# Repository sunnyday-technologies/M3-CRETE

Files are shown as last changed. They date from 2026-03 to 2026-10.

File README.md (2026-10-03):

# M3-CRETE — Experimental Open-Hardware Concrete/Paste Printing Reference

**A meter-scale cartesian motion reference for qualified technical teams working
with cementitious material extrusion in controlled R&D, laboratory, or
supervised institutional settings.**

M3-CRETE is an experimental open-hardware reference design, not a consumer
product, hobby kit, finished machine, certified construction printer, or
structural concrete production system.

Read first:

- [Safety Notice](SAFETY_NOTICE.md)
- [Electrical Scope Boundary](ELECTRICAL_SCOPE_BOUNDARY.md)
- [Disclaimer](DISCLAIMER.md)

The public release is limited to mechanical design information, low-voltage
control-interface references, and software/firmware references where published.
It does not include AC mains wiring instructions, control-panel build
instructions, facility-connection instructions, safety-rated emergency-stop
circuit designs, 48 V high-current distribution design, or code-compliance
instructions.

**M³** = **M**obile · **M**odular · **M**eter³



Developed by [Sunnyday Technologies](https://sunn3d.com).

| Spec | Value |
|---|---|
| **Open BOM component target** | Under $5,000 for public mechanical/low-voltage reference components where current commodity pricing and substitutions allow; professional electrical/power-control scope is excluded |
| **Configured design envelope** | Default M3-2 target: 2000 × 1000 × 1000 mm. The assembled external footprint and shipping configuration have not been physically verified here. |
| **Printhead weight** | ~1.5 kg |
| **License** | CERN-OHL-W-2.0 |

---

## Why M3-CRETE

Most concrete 3D printers are either proprietary industrial systems or one-off
research machines tied to specific institutions. M3-CRETE targets the space
between: an open mechanical and controls reference that qualified teams can
study, adapt, and validate within their own controlled research or development
programs.

### Target Applications

- Non-structural research specimens
- Process-development articles
- Digital formwork, molds, and fixtures
- Controlled materials and toolpath studies
- Laboratory and supervised institutional demonstrations
- Non-structural prototype objects where separately reviewed

Printed outputs require separate physical validation. No printed output from an
M3-CRETE-derived system may be used for structural, load-bearing, life-safety,
building-code, transportation, water-control, pressure-containing, occupied,
public-access, or permanent construction use unless separately designed, tested,
permitted, and approved by the responsible licensed professionals and
authorities for that specific project.

---

## Design Principles

### Mechanical Rigidity, Serviceability

The frame is engineered closer to CNC machine standards than desktop 3D
printers: rigid, durable, and precise. Mechanical components use standard
aluminum extrusions and commodity hardware where practical, so qualified teams
can inspect, replace, and modify parts without single-source dependency.

### Lower Moving Mass, Still Hazardous

The current drive system is sized for the reference geometry using project
calculations and component assumptions that still require physical commissioning
and load validation. This does not make the machine safety-rated or safe for
unsupervised use. Moving axes, pinch/crush hazards, cementitious materials,
pressurized hoses, electrical systems, and software-controlled motion all
require qualified review, guarding, PPE, training, and operating procedures.

### No Thermoplastic Melt System

Cementitious materials harden through hydration rather than thermoplastic melting and cooling, so the reference design does not use an FDM-style heated bed, hot end, or part-cooling system. That removes one class of hardware, but this repository does not establish a quantified cost, energy, or reliability advantage over other printer architectures.

### Designed for Research Iteration

Some non-structural components such as brackets, guides, and enclosure parts are
designed to be 3D-printable. Those printed parts still require inspection,
material selection, and project-specific validation before use in a working
machine.

---

## Firmware and Software Compatibility

M3-CRETE runs on established open-source toolchains. No proprietary software required.

| Layer | Compatible Tools |
|---|---|
| **Firmware** | Marlin, Klipper |
| **Slicers** | Cura, OrcaSlicer, PrusaSlicer |
| **Controls** | Standard stepper drivers, common control boards |
| **CAD/CAM** | Any tool that exports STL, OBJ, or 3MF |

Standard G-code workflows provide full, transparent control over toolpaths, layer heights, and extrusion parameters.

Firmware configurations are maintained separately:
[M3-CRETE-FIRMWARE](https://github.com/sunnyday-technologies/M3-CRETE-FIRMWARE)

---

## Repository Structure

```
M3-CRETE/
├── CAD/
│   ├── M3-2_Assembly.step       # Development STEP assembly snapshot via LFS
│   ├── m3_2_assembly.py         # CadQuery assembly generator (source of truth)
│   ├── self_check.py            # 5-gate automated validation harness
│   ├── kinematics_eval.py       # Structural analysis (deflection, torque, belts)
│   ├── Custom/                  # 3D-printable brackets (STEP + STL)
│   ├── Components/              # OpenBuilds parts library (CC BY-SA 4.0)
│   └── Advanced/                # Extended parts (C-beam, joining plates)
├── bom/
│   ├── data.json                # BOM source of truth (v2.7.0; 65 reference entries)
│   └── index.html               # Interactive BOM viewer (bom.m3-crete.com/bom)
├── firmware/                    # Klipper configs (kinematics, steppers)
├── blog/                        # Build logs and project updates
└── config.js                    # Model variants (M3-1, M3-2, M3-4)
```

### AI-Assisted CAD Workflow

This project uses [CADCLAW](https://github.com/sunnyday-technologies/CADCLAW), an automated checking framework for STEP CAD developed during this project. A declarative assembly spec places authored STEP parts by connector frames and datum chains, while software checks inspect selected inventory, interference, adjacency, dimensional, orientation, and floating-part rules. CADCLAW places parts authored in native CAD; it does not generate geometry. These checks are bounded software evidence, not proof of manufacturability, structural performance, tolerance compliance, safety, or physical fit.

See the [CADCLAW repo](https://github.com/sunnyday-technologies/CADCLAW) for the generalized, reusable framework.

---

## Material Compatibility

M3-CRETE is a hardware reference, not a materials approval. It does not
prescribe a construction mix, validate printed outputs, or certify any
cementitious formulation for field use. Mixes, toolpaths, curing, durability,
and acceptance criteria require separate physical testing and professional
review for each use case.

For early-stage materials-evidence and mix-design decision support, see
[CEMFORGE](https://cemforge.ai/concrete-printers/). Where sufficient source
evidence exists, it can help organize candidate formulations for review; it does
not establish a mix's performance or fitness. Every candidate requires physical
testing, provenance review, and qualified approval before project use.

---

## Project Status

M3-CRETE is in active development. Current focus areas:

- Finalizing the open BOM and build documentation
- Validating open assembly notes and build sequence
- Establishing firmware profiles for concrete-specific extrusion parameters

Interested in contributing design feedback, supplier corrections, or controlled
build notes?
Open an issue or start a GitHub discussion.

---

## Disclaimer

M3-CRETE is provided as-is for experimental, educational, and development
purposes. Concrete/paste printing involves moving machinery, cementitious
materials, pressurized material handling, and electrical systems that pose real
safety risks. Users assume all responsibility for safe design, construction,
commissioning, guarding, training, inspection, and operation of any system built
from these files.

### Electrical / AC Mains Boundary

Any AC mains wiring, control-box integration, grounding, bonding, overcurrent
protection, disconnects, emergency-stop power circuits, facility connection,
inspection, or code compliance work must be performed by qualified personnel, a
licensed electrician where required, or a qualified control-panel shop.

The public M3-CRETE files may identify electrical interfaces, low-voltage
controls, and component references, but they are not AC mains wiring
instructions, control-panel build instructions, or a substitute for applicable
electrical codes, authority-having-jurisdiction review, or professional
electrical judgment.

See [SAFETY_NOTICE.md](SAFETY_NOTICE.md),
[ELECTRICAL_SCOPE_BOUNDARY.md](ELECTRICAL_SCOPE_BOUNDARY.md), and
[DISCLAIMER.md](DISCLAIMER.md) for full details.

---

## License

This project is licensed under the **CERN Open Hardware Licence Version 2 — Weakly Reciprocal** ([CERN-OHL-W-2.0](https://ohwr.org/cern_ohl_w_v2.txt)).

You may use, modify, and distribute this design under the terms of that license. Modifications to covered files must be made available under the same license. This project includes no warranty of any kind.

**Dual License Notice:** V-Slot component CAD models in `CAD/Components/` are based on [OpenBuilds](https://openbuilds.com) designs and are licensed under [CC BY-SA 4.0](https://creativecommons.org/licenses/by-sa/4.0/). All other project files (custom parts, BOM viewer, firmware configs, documentation) are licensed under CERN-OHL-W-2.0.

See [LICENSES/](LICENSES/) for full license texts.

---

## Related Projects and Resources

| Resource | Description |
|---|---|
| [Convergence Engineering whitepaper](https://doi.org/10.5281/zenodo.19863080) | Methodology paper that uses M3-CRETE as a public case study; introduces the *time to silence* metric. CC BY 4.0 preprint, Zenodo. |
| [Sunnyday Technologies](https://sunn3d.com) | Parent company — concrete 3D printing and engineered cementitious composites |
| [M3-CRETE Project Page](https://sunn3d.com/m3-crete/) | Hosted project overview and Sunnyday contact path |
| [CADCLAW](https://github.com/sunnyday-technologies/CADCLAW) | Automated STEP assembly compilation and validation, extracted from this project |
| [CEMFORGE™](https://cemforge.ai/concrete-printers/) | AI-powered concrete formulation platform by Sunnyday Technologies |
| [M3-CRETE Firmware](https://github.com/sunnyday-technologies/M3-CRETE-FIRMWARE) | Firmware configurations for Klipper |

---

## Author

**Nicholas Sonnentag** ([ORCID 0009-0002-1897-384X](https://orcid.org/0009-0002-1897-384X)) — mechanical engineer, founder of [Sunnyday Technologies](https://sunn3d.com). M3-CRETE is designed and maintained by Nick; CAD iteration is LLM-assisted but the engineering judgment, component selection, build decisions, and direction are his.

- LinkedIn: [Nicholas Sonnentag](https://www.linkedin.com/in/nicholas-sonnentag)
- Email: `info@sunn3d.com`

## Citation

If you use M3-CRETE designs in research, a controlled build, or derivative
work, please cite:

```
Sonnentag, N. (2026). M3-CRETE: Open-Source Concrete 3D Printer.
Sunnyday Technologies.
https://doi.org/10.5281/zenodo.19647435
```

For the methodology paper that uses M3-CRETE as a public case study, cite:

```
Sonnentag, N. (2026). Convergence Engineering: Commissioning Autonomous
Software by Measuring the Rate at Which Novel Failures Trend Toward Zero.
Sunnyday Technologies. https://doi.org/10.5281/zenodo.19863080
```

A [`CITATION.cff`](CITATION.cff) file is included for automated citation tooling.

## Contributing

We welcome issues, pull requests, and design feedback from qualified teams. If
you are working with cementitious extrusion in a controlled technical setting,
your experience is valuable — open an issue or start a
[discussion](https://github.com/sunnyday-technologies/M3-CRETE/discussions).

**Contact:** info@sunn3d.com

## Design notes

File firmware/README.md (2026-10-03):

# M3-CRETE Firmware

Klipper configuration for the M3-CRETE concrete 3D printer motion system.

## What's in this directory

| File | Purpose |
|---|---|
| `printer.cfg` | Top-level entry point — includes every other file |
| `mcu.cfg` | BTT Kraken MCU connection (serial path) |
| `kinematics.cfg` | Cartesian kinematics, build volume, motion limits |
| `steppers.cfg` | 7 motion steppers (X, 2×Y, 4×Z) + extruder/pump |
| `tmc.cfg` | TMC5160 driver settings — currents, StallGuard thresholds |
| `homing.cfg` | Sensorless homing sequence (no physical endstops) |
| `z_tilt.cfg` | Quad Z self-tramming |
| `macros.cfg` | START_PRINT, END_PRINT, pump priming, pump flush, pressure advance |
| `input_shaper.cfg` | ADXL345 + resonance tester + input shaper (optional include) |

## Hardware assumed

- **Controller:** BTT Kraken v1.0 (STM32H723, 8× onboard TMC5160)
- **Host:** Raspberry Pi 5 8GB running Klipper + Moonraker + Mainsail
- **Motion steppers:** 7× NEMA23 3–4.5Nm, 8mm shaft (1×X + 2×Y + 4×Z)
- **Nozzle valve:** 1× small stepper (NEMA17/23) on Kraken DRIVER7
- **Feed pump:** 1× NEMA34 on external driver (owner-supplied)
- **Y/Z belts:** GT2 10mm + 20-tooth pulleys (looped)
- **X belt:** GT2 6mm + 20-tooth pulley (fixed strand, pinion drive)
- **V-wheels:** Polycarbonate, eccentric-spacer adjustable
- **Homing:** Sensorless StallGuard on all axes — no physical endstops

## Axis conventions & motor layout

Frame origin `(0, 0, 0)` is at the **front-left corner of the build surface**. Looking down from above:

```
              X=0                                      X=2000
             ┌──────────────────────────────────────────┐    Y=1000
             │ Z2◆                                 Z3◆ │    (REAR)
             │                                          │
             │                                          │  ← Y motors
             │                                          │    (2× at rear,
             │                                          │     inboard of
             │           BUILD VOLUME                   │     rear Z-posts)
             │         2000 × 1000 × 1000 mm             │
             │                                          │
             │                                          │  ← X motor
             │                                          │    on X-carriage
             │                                          │    (pinion drive,
             │                                          │     travels with
             │ Z0◆                                 Z1◆ │     the printhead)
             └──────────────────────────────────────────┘    Y=0
                                                             (FRONT, HOME)

             ← X−                                     X+ →
                HOME

  ◆ = Z motor (NEMA23) on top brace, straddling each 4080 C-beam Z-post
      (4 motors total, each with its own StallGuard-based homing)
```

### Home positions (all sensorless — no physical endstops)

| Axis | Home direction | Home position | Stall target |
|---|---|---|---|
| X | toward X− | X = 0 | left frame post |
| Y | toward Y− | Y = 0 | front Z-posts frame |
| Z | toward Z+ | Z = 1000 | top brace (per post)|

**Homing sequence** (set in `homing.cfg`):

1. **Z first** — all 4 Z posts drive UP into the top brace in parallel. Each post's StallGuard fires independently on its own driver, giving per-corner coplanarity without a physical probe.
2. **X second** — the development sequence assumes Z reached its configured reference position before an X-axis stall-detection move; this is not a verified safe-height guarantee.
3. **Y last** — both Y motors drive the gantry forward into the front frame until the primary stalls (the secondary follows).

### Why Z first

If X or Y moves with Z at an unknown position, the printhead can contact an obstacle. The current development sequence attempts to establish a Z reference first, but stall sensing and a hard stop do not guarantee clearance, repeatability, safe force, or a clear path. A qualified commissioning plan must verify the actual envelope, obstructions, speeds, currents, stopping behavior, guarding, and recovery before any automated homing sequence is enabled.

### Development motion references (not validated safe limits)

| Parameter | Value | Notes |
|---|---|---|
| `max_velocity` | 100 mm/s | Tune up after input shaping |
| `max_accel` | 1500 mm/s² | Concrete mass demands gentle accel |
| `max_z_velocity` | 25 mm/s | Z belts, not leadscrews |
| `max_z_accel` | 300 mm/s² | |
| `square_corner_velocity` | 5.0 mm/s | Low to prevent belt slip on corners |

## Build from source (Klipper firmware for the Kraken)

On the Raspberry Pi:

```bash
cd ~
git clone https://github.com/Klipper3d/klipper.git
cd klipper
make menuconfig
```

In `menuconfig`, set:

```
Micro-controller Architecture ........... STMicroelectronics STM32
Processor model ......................... STM32H723
Bootloader offset ....................... 128KiB bootloader
Clock Reference ......................... 25 MHz crystal
Communication interface ................. USB (on PA11/PA12)
```

Save and exit, then:

```bash
make
```

The compiled firmware lands at `~/klipper/out/klipper.bin`.

## Flashing the Kraken

1. Copy `klipper.bin` to a FAT32-formatted microSD card, renaming it to `firmware.bin`.
2. Power off the Kraken.
3. Insert the SD card.
4. Power on — the bootloader will flash automatically (~10 seconds).
5. On successful flash, `firmware.bin` will be renamed to `FIRMWARE.CUR` on the card.

## Installing this config

1. Copy this entire `firmware/` directory to `~/printer_data/config/` on the Pi.
2. Rename `printer.cfg` to the name Moonraker expects (default: `printer.cfg` in that directory — leave it as-is if you copied the folder contents directly).
3. Edit `mcu.cfg` — replace the `XXXXXXXXXXXXXXXX` placeholder with the real serial ID. Find it with:

   ```bash
   ls /dev/serial/by-id/
   ```

4. Restart Klipper via Mainsail (**Machine** → **Restart**) or:

   ```bash
   sudo systemctl restart klipper
   ```

## First-boot checklist

Do these in order, one at a time, before any actual printing.

### 1. Verify MCU connection

```
RESTART
FIRMWARE_RESTART
```

Klipper should report "Ready" in Mainsail. If it errors, check the serial path in `mcu.cfg`.

### 2. Power on one stepper at a time, verify motion direction

Using the Mainsail jog buttons, move each axis 10mm in its positive direction. Confirm:

- **X+** moves the gantry toward the **right** (looking at the front of the machine)
- **Y+** moves the gantry toward the **rear**
- **Z+** moves the gantry **up**

If any axis moves the wrong way, flip the `dir_pin` polarity in `steppers.cfg` by adding or removing the `!` prefix.

### 3. Verify Y dual-drive synchronization

Jog Y by 100mm. The left and right Y rails must move together — if one lags, they're not synced. Check that `stepper_y1` has the same `rotation_distance` and `microsteps` as `stepper_y`.

### 4. Calibrate rotation_distance per axis

Mark a starting point with tape. Jog the axis exactly 100mm via Mainsail. Measure with a tape measure. If the actual distance is off, adjust `rotation_distance` proportionally:

```
new_rotation_distance = old_rotation_distance × (actual / requested)
```

### 5. Tune StallGuard thresholds (sensorless homing)

This is the trickiest part. For each axis, iterate:

1. Issue `G28 X` (or Y or Z).
2. Watch the motion:
   - **Stalls before reaching the frame** → `driver_SGT` is too sensitive → **increase** by 1 in `tmc.cfg`
   - **Crashes into the frame without stalling** → `driver_SGT` is not sensitive enough → **decrease** by 1
3. Restart Klipper (`FIRMWARE_RESTART`) after each change.
4. Repeat until homing stops reliably at the frame.

Use the `SHOW_SG` macro to see live StallGuard values while the printer is idle.

### 6. Test quad Z homing

The first `G28 Z` will drive all 4 Z posts UP into the top brace. Each post stalls independently when its corner meets the brace — you should hear 4 distinct "thunks" over about a second. If one corner doesn't stall, its `driver_SGT` is too high; lower it.

### 7. Calibrate the nozzle valve and feed pump independently

Because the two steppers are synced, you have to calibrate them one at a time.

**Step 7a — Feed pump (`pump_feed`):**

1. `PUMP_UNSYNC` (disconnect the pump from the valve)
2. Disconnect the hose from the nozzle and route it into a measuring cup
3. `G1 E100 F60` (runs only the pump, valve stays closed)
4. Measure the output volume
5. Scale: `new_rotation_distance = old × (commanded / actual)`
6. Edit `steppers.cfg` → `[extruder_stepper pump_feed]` → `rotation_distance`
7. `FIRMWARE_RESTART`
8. `PUMP_RESYNC`

**Step 7b — Nozzle valve (`extruder`):**

1. With hose reconnected and pump running synced, command `G1 E100 F60`
2. Measure what comes out the nozzle
3. If pump output is already calibrated and valve output is off, scale the valve's `rotation_distance` (in `[extruder]`) using the same formula
4. `FIRMWARE_RESTART`

In practice the valve rarely needs precise calibration — it's a metering gate, not a volumetric pump — but doing both ensures the two are in agreement.

### 8. Test a small print

Use a 10cm × 10cm single-wall square at a slow speed (30 mm/s) for the first print. Check:

- First-layer adhesion and squish
- Belt tension (no slapping or visible stretch under accel)
- Pump flow consistency

## Pump architecture — feed pump + nozzle valve

M3-CRETE uses a two-stage fluid-handling system:

- **Feed pump** (`pump_feed`) — the big NEMA34 upstream of the hose. Has its own pressure advance (typical 0.5–1.5 seconds) to pressurize the hose ahead of valve commanded moves. Runs on an external driver via Kraken's MOTOR7 header.
- **Nozzle valve** (`extruder`) — a small, fast actuator at the printhead. Pressure advance = 0. Effectively a metering valve with ~1 % retraction capability for clean corners. Runs on Kraken's DRIVER7 onboard TMC5160.

Both steppers are synchronized: every `G1 E...` move drives both at once. The feed pump runs *ahead* of the valve in time (by the amount of its pressure advance) so material arrives at the valve exactly when it opens.

### Why independent pressure advance matters

Concrete hoses are compressible and viscous — unlike a rigid FDM filament path, the pressure in the hose lags the pump by hundreds of milliseconds. If you drove the pump and valve with the same PA, the valve would either dribble (if PA is low) or over-pressurize at corners (if PA is high). Splitting them means:

- **Valve PA = 0** → opens and closes on time, clean corners
- **Pump PA = 0.8** → hose is already pressurized when the valve opens

### Tuning

Use the `SET_PUMP_PA` macro during a test print:

```
SET_PUMP_PA ADVANCE=0.5    ; start here
; print a corner-test pattern, observe
SET_PUMP_PA ADVANCE=0.8    ; increase if corners dribble after direction change
SET_PUMP_PA ADVANCE=0.3    ; decrease if corners bulge before direction change
```

The default in `START_PRINT` is `ADVANCE=0.8`. Edit `macros.cfg` once you've found your hose's sweet spot.

### Independent pump control

To run the feed pump solo (e.g. manually fill the hopper without opening the valve):

```
PUMP_UNSYNC           ; feed pump disconnects from valve
; jog pump manually via G1 E... — only pump moves
PUMP_RESYNC           ; feed pump reconnects for normal printing
```

## Safety notes

- **Flush the pump line within 5 minutes of print completion.** Concrete cures inside the line and will lock the pump solid.
- **StallGuard homing is not foolproof.** If you're standing inside the machine's envelope, always power off the motors first.
- **Test all motion at low current first** (`run_current: 1.2` in `tmc.cfg`) and raise in 0.2A increments after verifying thermal behavior.
- **The X axis is 2m long and heavy.** Homing speeds above 30 mm/s will cause belt slip before the frame is reached.

## Input shaping (ADXL345)

A 2m concrete printer has long belt spans that resonate at low frequencies — without input shaping, corner moves leave visible ringing for several cm. The `input_shaper.cfg` file is a drop-in module that enables Klipper's resonance measurement + compensation workflow using an ADXL345 accelerometer wired to the Raspberry Pi's GPIO SPI bus.

**Setup is a three-step thing:**

1. **Buy the part** — it's BOM item 71 (ADXL345, ~$10 from BTT/Adafruit/Amazon). Mount it rigidly to the printhead or X-carriage using M3 screws. Zip ties will give you garbage data.

2. **Wire it** — 6 wires from the breakout to the Pi's 40-pin header. The full pinout is in `input_shaper.cfg` at the top of the file. TL;DR: power + SPI on Pi pins 1, 9, 19, 21, 22, 23.

3. **Enable the include** — uncomment the `[include input_shaper.cfg]` line in `printer.cfg`, then follow the setup procedure inside `input_shaper.cfg` (enable SPI on the Pi, install the host MCU, run `SHAPER_CALIBRATE`).

Klipper's `SHAPER_CALIBRATE` will sweep the printer and print recommended `shaper_freq_x` / `shaper_freq_y` values. Paste those into the `[input_shaper]` section at the bottom of `input_shaper.cfg` and `FIRMWARE_RESTART`.

After tuning, you can leave the ADXL345 installed or remove it — the input shaper values stay in the config either way.

## Known limitations (v0.1)

- **No physical probe** — Z_TILT_ADJUST is stubbed out until a probe is wired in. First-layer calibration is currently manual.
- **Pin assignments for BTT Kraken are based on the upstream `example-kraken.cfg`** — verify against your board revision on first boot.
- **Extruder `rotation_distance` is a placeholder** — must be calibrated against your specific pump geometry.
- **Input shaping not yet tuned.** Add an ADXL345 to the toolhead mount and run `SHAPER_CALIBRATE` after mechanical commissioning.

## Contributing

This config is part of the M3-CRETE project: <https://github.com/sunnyday-technologies/M3-CRETE>

Licensed under CERN-OHL-W-2.0. Issues and PRs welcome at the repo above.

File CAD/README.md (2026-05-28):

# M3-CRETE CAD Files

3D models for the M3-CRETE concrete 3D printer motion system.

## Assembly (Draft v0.1 — In Development)

The M3-2 digital twin assembly is generated programmatically from the STEP
component library using CadQuery + Python. This is believed to be the first
AI-assisted multi-part mechanical assembly generated from real vendor STEP files.

**Status:** Draft v0.1 — frame structure complete, motion system in progress.

### Source of Truth: `m3_2_assembly.py`

`CAD/m3_2_assembly.py` is the **canonical source** for the M3-2 assembly. The
`.step` files in this directory (and any `.f3d`) are **derived outputs**
generated by running the script — they are not the source.

To modify the design, edit parameters in `m3_2_assembly.py` and regenerate the
STEP. Do **not** hand-edit the STEP files and expect changes to persist; the
next regen will overwrite them.

This satisfies the CERN-OHL-W-2.0 requirement to distribute the preferred form
for modification: the parametric Python script is human-readable, diffable, and
tool-agnostic — a better open-source workflow than shipping a binary Fusion 360
file that requires a specific version of proprietary software to open.

```
python CAD/m3_2_assembly.py          # Generates M3-2_Assembly.step
python CAD/parametric_extrusions.py  # Generates custom-length extrusions
python CAD/deep_probe.py             # Inspects STEP geometry for assembly math
```

**Requirements:** Python 3.11 + CadQuery 2.7.0 (`pip install cadquery`)

**Assembly contents (40 parts):**
- 4x C-Beam 4080 posts (1000mm, full height)
- 8x C-Beam 4080 top X-rails (1000mm segments, spliced)
- 5x C-Beam 4080 Y-braces (1000mm)
- 2x C-Beam 4080 Y-rails (1000mm)
- 2x C-Beam 4080 gantry beam (1000mm, spliced to 2000mm)
- 8x gantry plates (Z-carriage, sandwich posts)
- 4x gantry plates (X-carriage + Y-rail end plates)
- 7x NEMA23 motors (4Z horizontal + 2Y inside + 1X on carriage)
- 4x motor mount plates

**Open-bottom bridge frame** — no front/back bottom rails, allowing the printer
to straddle walls for continuous printing.

## Directory Structure

```
CAD/
├── Components/     Standard parts (OpenBuilds-compatible, CC BY-SA 4.0)
│   ├── V-Slot/         Extrusion profiles (4080 C-Beam primary)
│   ├── Plates/         Gantry plates, motor mounts, idler plates
│   ├── Wheels/         V-wheels (Delrin, Xtreme, idler pulleys)
│   ├── Bearings/       625-2RS, 688Z ball bearings
│   ├── Brackets/       Corner brackets, actuator end mounts
│   └── Hardware/       Eccentric spacers, shims, T-nuts
├── Custom/         Sunnyday-designed parts (CERN-OHL-W-2.0)
│   ├── Frame-Stiffener.step
│   └── Extruder-Mount-NPT.step
└── Advanced/       Compatible hardware for extended builds
    └── (alternative extrusion profiles, reinforcement options)
```

## Format

Component parts (`Components/`, `Advanced/`) and custom parts (`Custom/`) are
provided in **STEP** format (.step / .stp) for maximum compatibility with
FreeCAD, Fusion 360, SolidWorks, Onshape, and other CAD tools.

The **M3-2 assembly itself** uses the parametric Python script
(`m3_2_assembly.py`) as its source format, with `M3-2_Assembly.step` as the
generated output (see "Source of Truth" above).

## Component Parts — Sources

The standard V-Slot components in `Components/` are based on the [OpenBuilds](https://openbuilds.com) parts ecosystem, licensed under **CC BY-SA 4.0**.

### Where to Get STEP Files

If a part is not yet in this repo, you can download STEP models from:

| Source | URL | Notes |
|---|-----|---|
| **GrabCAD — OpenBuilds Gantry Set** | [grabcad.com/library/openbuilds-v-slot-gantry-set-all-sizes-1](https://grabcad.com/library/openbuilds-v-slot-gantry-set-all-sizes-1) | Complete gantry assemblies, all V-Slot sizes |
| **GrabCAD — V-Slot Tag** | [grabcad.com/library/tag/v-slot](https://grabcad.com/library/tag/v-slot) | Individual parts and assemblies |
| **Printables — Universal Gantry Plate** | [printables.com/model/459195](https://www.printables.com/model/459195-openbuilds-v-slot-gantry-plate-universal) | STL for 3D printing |
| **StepperOnline — NEMA23 Models** | [omc-stepperonline.com/download](https://www.omc-stepperonline.com/download) | Motor STEP files by MPN |
| **BTT — Kraken Board** | [github.com/bigtreetech/Kraken](https://github.com/bigtreetech/Kraken/tree/master/Hardware) | Controller board models |

### M3-CRETE Part Count

The M3-2 uses approximately **20 unique component types** (many repeated):

| Component | Unique Models | Total Qty |
|---|---|---|
| C-Beam 4080 extrusions | 1 (4080 C-Beam) | ~17 segments |
| Gantry/carriage plates | 3 types | 12 plates |
| Motor mounts | 1 type | 8 mounts |
| V-wheels | 2 types | 36 wheels |
| GT2 pulleys | 2 types | 20 pulleys |
| Bearings/spacers | 3 types | 28+ pieces |
| Custom parts | 2 (stiffener, extruder mount) | 5 parts |

## License

- **Components/** — CC BY-SA 4.0 (based on OpenBuilds designs, attribution required)
- **Custom/** — CERN-OHL-W-2.0 (same as M3-CRETE project)
- **Advanced/** — Mixed, see individual files

## Contributing

**To modify the M3-2 assembly:** Edit `m3_2_assembly.py` (the canonical
source), regenerate `M3-2_Assembly.step`, and commit both. Do not edit the
STEP directly.

**To add a new component model:**
1. Export as STEP (.step or .stp)
2. Name it to match the BOM part name
3. Place in the appropriate directory (`Components/`, `Custom/`, or `Advanced/`)
4. Submit a Pull Request

Models are linked to the [BOM Viewer](https://bom.m3-crete.com/bom/) via the `step_url` field in `bom/data.json`.

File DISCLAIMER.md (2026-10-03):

# DISCLAIMER

M3-CRETE is provided as open-source hardware for experimental, educational, and
development purposes.

Related project-scope documents:

- [Safety Notice](SAFETY_NOTICE.md)
- [Electrical Scope Boundary](ELECTRICAL_SCOPE_BOUNDARY.md)

**It is not certified for structural, safety-critical, or code-compliant applications.**

## Safety Notice

Concrete/paste printing involves moving machinery, cementitious materials,
pressurized material handling, and electrical systems that pose real safety
risks. Responsibility and legal duties depend on the parties, jurisdiction, and
actual use. Anyone considering construction or operation must identify competent
owners for design, commissioning, guarding, training, inspection, and operation
and obtain applicable professional and legal review.

## Electrical And AC Mains Work

Any AC mains wiring, control-box integration, grounding, bonding, overcurrent protection, disconnects, emergency-stop power circuits, facility connection, inspection, or code compliance work must be performed by qualified personnel, a licensed electrician where required, or a qualified control-panel shop.

The public M3-CRETE files may identify electrical interfaces, low-voltage
controls, and component references, but they are not AC mains wiring
instructions, control-panel build instructions, or a substitute for applicable
electrical codes, authority-having-jurisdiction review, or professional
electrical judgment. Do not energize any M3-CRETE-derived system unless the
electrical work has been reviewed and accepted for the intended environment.

The public release does not include AC mains design, 48 VDC or other
high-current power-distribution design, safety-rated control design,
emergency-stop power-circuit design, control-panel construction, facility
wiring, or UL/NRTL/AHJ approval.

## No Warranty

Sunnyday Technologies makes no representations or warranties of any kind — express or implied — regarding the fitness of these designs for any particular purpose, their completeness, accuracy, or suitability for any use. All designs are provided as-is.

## Limitation of Liability

To the maximum extent permitted by applicable law and subject to the governing
licenses, Sunnyday Technologies disclaims liability for injury, property damage,
loss, or other harm resulting from use, misuse, or inability to use these files
or a system derived from them. Nothing here excludes rights or liabilities that
cannot lawfully be excluded.

## Regulatory Compliance

Users are solely responsible for ensuring compliance with all applicable local
building codes, electrical codes, structural standards, and safety regulations
before constructing or operating any system based on these files. Nothing in
this repository constitutes engineering advice, professional sign-off, or
regulatory approval.

This notice is informational and does not create professional services,
engineering approval, certification, or a click-through agreement. The exact
open-source licenses govern licensed files. Obtain qualified legal advice for
commercial distribution, workplace use, construction use, or questions about
local obligations.

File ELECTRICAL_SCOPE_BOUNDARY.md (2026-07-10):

# M3-CRETE Electrical Scope Boundary

The public M3-CRETE release is limited to mechanical design information,
low-voltage control-interface references, and software/firmware references
where published. The public release does not include AC mains design, 48 VDC or
other high-current power-distribution design, safety-rated control design,
emergency-stop power-circuit design, control-panel construction, facility
wiring, or UL/NRTL/AHJ approval.

Any certified, listed, field-evaluated, or inspected power/control enclosure is
a separate professional scope and applies only to the exact configuration
evaluated. Certification of a power/control enclosure does not certify the
complete M3-CRETE machine, installation, printed output, site, operating
procedure, or downstream modifications.

## Public content allowed

- Mechanical design references.
- Low-voltage interface boundaries where values are reviewed and marked.
- Software and firmware references where published.
- Warnings that identify professional electrical, control-panel, safety, and
  authority-review responsibilities.

## Public content not provided

- AC line, neutral, or protective-earth wiring.
- Power-supply primary-side wiring.
- Branch-circuit, breaker, contactor, disconnect, or facility-connection
  wiring.
- Safety-rated emergency-stop power-circuit implementation.
- 48 VDC or other high-current power-distribution design.
- Control-panel construction drawings or netlists.
- Claims that any panel mark certifies the whole machine or installation.

## Professional review required

Before energizing or operating any M3-CRETE-derived system, qualified
professionals must review and accept the electrical power system, controls,
machine guarding, emergency-stop behavior, grounding/bonding, overcurrent
protection, facility connection, inspection basis, and operating procedures for
the actual installation and intended environment.

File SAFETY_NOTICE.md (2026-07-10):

# M3-CRETE Safety Notice

## Experimental open-hardware reference design, not a certified product

M3-CRETE is not a consumer product, not a hobby kit, not a finished machine,
not a certified construction printer, and not a structural concrete production
system. It is an experimental reference design for qualified technical teams
working in controlled R&D, laboratory, or supervised institutional settings.

Sunnyday Technologies does not provide public AC mains wiring instructions,
control-panel build instructions, facility-connection instructions,
safety-rated emergency-stop circuit designs, or code-compliance instructions.
Any electrical power system, control panel, grounding/bonding system,
disconnect, overcurrent protection, emergency-stop power circuit, machine
guarding, facility connection, inspection, certification, field evaluation, or
AHJ review must be designed, built, inspected, and accepted by qualified
professionals for the specific installation and intended environment.

## No structural use without separate project review

M3-CRETE does not certify, approve, warrant, or validate any printed concrete,
mortar, paste, structure, component, repair, form, mold, or construction method.
No printed output from an M3-CRETE-derived system may be used for structural,
load-bearing, life-safety, building-code, transportation, water-control,
pressure-containing, occupied, public-access, or permanent construction use
unless separately designed, tested, permitted, and approved by the responsible
licensed professionals and authorities for that specific project.

## User responsibility

Users and integrators are responsible for the workspace, guarding, personal
protective equipment, lockout/tagout procedures, operator training, material
handling, machine commissioning, professional electrical review, local-code
review, and any project-specific engineering or authority review.

This notice is a public project-scope boundary. It is not legal advice,
electrical engineering approval, product-safety certification, or authority
having jurisdiction approval.

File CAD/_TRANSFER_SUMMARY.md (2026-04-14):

# M3-CRETE CAD — Session Transfer Summary

**Source session:** `746b75e6-fe00-404a-9578-a5e590a7d0bb.jsonl`
**Last activity:** 2026-04-11 13:08 UTC
**Branch/HEAD:** `main` @ `e04d6c5` (pushed) + uncommitted C.3 refactor work

---

## Where we are

- **74 parts, 0 interferences, 290/290 invariants passing** (as of msg 645, before latest parametric refactor).
- Phases C.1 (Z-motors) + C.2 (Z-idlers) + C.3 (Z-belts) **complete and pushed** as `3f29c09` (v0.3.0) and `e04d6c5` (track `.f3d`).
- Nick moved the **RL Z-motor + belts outbound** (outside frame envelope) in `M3-2_Assembly_user.step` to free interior volume for the Y-motor in C.4. Claude mirrored this in `m3_2_assembly.py` via a signature-based loader + a `RELOCATED={"RL"}` relaxation set.
- Nick then (msg 649) asked to extend this fix to **all 4 corners**: move the RL idler outbound too, widen belt gap from ±3.5mm to ±6.5mm (pulley width) on all corners, then commit/push before C.4.
- Claude started a **full parametric C.1→C.3 refactor** (msgs 651–666) so belts & idlers derive from loaded pulley positions — auto-follows any manual moves, widened gap applies globally, RL special-case removed.
- After refactor: **0 interferences, 74 parts, 16 s gen time**, but **5 invariant failures** on the RL idler because axle rotated from X to Y (dims became 22×12.7×22 instead of 12.7×22×22).
- Claude updated [CAD/preview_assembly.py](CAD/preview_assembly.py) idler invariants (msg 671) to match the new axle orientation. **Self-check re-run was started in background** (task `b9wxmhwwu`) and **never retrieved** — session ended mid-`wait`. Check the temp file or just re-run the self-check.

---

## IMMEDIATE next steps (resume here)

1. **Confirm the background self-check passed.** Re-run:
   ```
   cad_venv/Scripts/python.exe CAD/preview_assembly.py 2>&1 | tail -15
   ```
   Expect `XXX/XXX invariants pass` and no failures. If failures remain, they are all on the newly parametric C.2/C.3 geometry — inspect and fix invariants (NOT the geometry — geometry was already interference-clean).

2. **Commit the refactor.** Suggested message:
   > `refactor(cad): parametric C.1-C.3 loaders; widen belt gap to ±6.5; relocate idlers to follow pulleys`
   Stage: `CAD/m3_2_assembly.py`, `CAD/preview_assembly.py`, `CAD/M3-2_Assembly.step` (regenerated, 14.4 MB).
   Do NOT stage `.pkl` debug files or `_preview/`.

3. **Push to origin/main.**

4. **Then start Phase C.4 — Y-axis motion.**

---

## Phase C.4 — Y-axis motion (AGREED plan, not yet started)

From msgs 648 (Claude proposal) + 649 (Nick confirmation) + 654 (Claude correction):

| # | Decision | Value |
|---|---|---|
| 1 | Y-motor count | **2** (one per Y-rail, dual-drive anti-racking) |
| 2 | Y-motor position along rail | **Rear** end of each Y-rail (near Y=1200) |
| 3 | Y-motor mount hardware | **Same OMC StepperOnline ST-M2 L-bracket** already used for Z-motors (BOM qty 4→6) |
| 4 | Y-motor orientation | **Shaft pointing DOWN**, rotation axis = **Z** (NOT X as Claude initially assumed) |
| 5 | Y-belt termination | Clamps to **X-beam carriage plate** (2 plates, one per rail). X-beam slides along Y; Z-corner plates stay Y-fixed relative to Y-rails |

**BOM update required:** Replace old "Nema 23 flat mounting plates" with the new L-brackets; qty rises to 6 total (4 Z + 2 Y).

**Phase C.8 note (future, not now):** X-motor will reuse the exact subassembly from `V Slot Belt and Pinion Actuator 500mm.step` (full V_Slot variant, NOT Mini V), scaled to full X-beam length. Probe that STEP file when C.8 starts.

---

## Design constraints (locked earlier, still binding)

- **Global envelope rule:** everything stays inside `X[40,2440], Y[20,1220], Z[40,1120]` — nothing may get sheared off during transport. (The RL Z-motor relocation violates this; covered by "safety boxes or something" per Nick msg 603. Flag for future cover design.)
- **Z-motors at TOP** of posts (mud/concrete splatter protection).
- **Motor mounting plates double as corner reinforcement** (structural role).
- Z-motor rotation axis parallel to X.
- Y-motors mounted inside frame envelope (except where the C.4 refactor forces exceptions).
- "Use all resources to the max" — design ethos for structural compromises.

---

## Standing self-verification harness

After **every** edit to [CAD/m3_2_assembly.py](CAD/m3_2_assembly.py):

1. `cad_venv/Scripts/python.exe CAD/m3_2_assembly.py` — must print `[OK] No solid interferences`. The `EXCLUDE_PAIRS` list inside the script declares intentional overlaps. Add to it only for documented butt-joints / wheel-rail engagements.
2. `cad_venv/Scripts/python.exe CAD/preview_assembly.py` — runs ~290 engineering invariants and writes orthographic PNGs to `CAD/_preview/view_xy.png|view_xz.png|view_yz.png`. Read the PNGs back with the Read tool to visually self-check.

Both must pass before declaring work done.

---

## Open questions / known issues carried forward

- **RL Z-motor protrudes outside envelope** (X<0) — needs a cover/safety box in a later phase. Not blocking C.4.
- **The C.3 parametric refactor is untested post-idler-invariant-fix** — that's item #1 above.
- **Possible 4.7° belt angle on other corners** if pulley auto-positioning doesn't perfectly match `M3-2_Assembly_user.step` — verify in `view_yz.png` after rebuild.

---

## Key files

- [CAD/m3_2_assembly.py](CAD/m3_2_assembly.py) — main assembly script (build123d/cadquery hybrid), ~74 parts, v0.3.0
- [CAD/preview_assembly.py](CAD/preview_assembly.py) — self-check harness (invariants + PNG render)
- [CAD/M3-2_Assembly.step](CAD/M3-2_Assembly.step) — generated output, 14.4 MB, **tracked in git** (users review without rebuilding)
- [CAD/M3-2_Assembly_user.step](CAD/M3-2_Assembly_user.step) — Nick's manually-edited source-of-truth for moved/reshaped parts; signature-loaded by the script
- [CAD/Vendor/StepperOnline/N23_angled_mount.STEP](CAD/Vendor/StepperOnline/N23_angled_mount.STEP) — the L-bracket used for both Z and Y motors
- [CAD/_preview/](CAD/_preview/) — bbox_table.txt + 3 orthographic PNGs (gitignored)
- [CAD/_preview/bbox_table.txt](CAD/_preview/bbox_table.txt) — authoritative bbox dump after last rebuild

---

## Memory pointers (already saved)

- `[session-path-redacted] — the self-check workflow
- `[session-path-redacted] — PartCAD/build123d ecosystem snapshot

No memory file exists yet for the C.4 plan or the parametric-loader refactor — worth creating one after C.4 lands.

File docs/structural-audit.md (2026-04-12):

# M3-2 Structural Audit

**Date:** 2026-04-12
**Input:** M3-2_AsXX.step (partial C-beam upgrade, 2/4 Z-motors relocated above top frame)
**Goal:** Identify the stiffest practical frame configuration given current design constraints

---

## 1. Load Paths

The M3-CRETE motion system produces these mechanical loads during operation:

| Source | Direction | Magnitude (peak) | Transmits through |
|---|---|---|---|
| X-axis accel (printhead moving) | X | ~5 N | Gantry beam → X-carriage plates → Z-platform Y-rails → Z-corner plates → Z-posts |
| Y-axis accel (gantry moving) | Y | ~10 N (dual-drive) | Z-platform Y-rails → Z-posts (as moment arm) |
| Z-axis lift (gantry weight + belt tension) | Z | ~60 N per post | Z-posts → top frame → base |
| Concrete hose drag | X, Y, Z | ~30 N | Printhead → gantry → all moving elements |

The **critical stiffness path** is the gantry reacting X/Y accelerations against the Z-posts. Post bending stiffness × top-rail connection stiffness governs overall ringing/resonance.

---

## 2. Extrusion Properties

Cross-section moment of inertia (about the critical bending axis) and per-meter weight:

| Profile | I_min (mm⁴) | I_max (mm⁴) | Area (mm²) | kg/m |
|---|---|---|---|---|
| V-Slot 2040 | ~23,000 | ~83,000 | ~270 | 0.72 |
| V-Slot 2080 | ~33,000 | ~353,000 | ~470 | 1.26 |
| **C-Beam 40×80** | **~130,000** | **~480,000** | ~500 | 1.35 |

**C-Beam is ~5.7× stiffer than 2040** about the weak axis, and ~1.36× stiffer than 2080 about the strong axis — the flanges of the C-shape add significant moment of inertia vs. an open V-slot profile.

For Z-post bending (which resists X/Y gantry accelerations transmitted through the Y-rails), the 2040 → C-Beam upgrade is a clear win: **~5.7× stiffer** for only +0.63 kg/m weight penalty.

---

## 3. Current Design Weaknesses (from AsXX.step)

### 3.1 Z-post bending (primary)
- Current 2040 posts: I_weak ≈ 23,000 mm⁴. Under a 50 N horizontal load at the gantry midpoint (Z=440), tip deflection at a free post top is δ = FL³/3EI ≈ 0.48 mm per post. **Ringing-grade stiffness.**
- **With C-Beam:** deflection drops to ~0.08 mm. **6× improvement.**

### 3.2 Top rail butt joints
- 4 top X-rails butt-join to 4 posts with no corner brackets.
- 2 top Y-rails butt-join to 2 posts at each end, also no brackets.
- Currently relies on end-tap screws only (M5 into rail end). Each screw has ~150 N/mm shear stiffness → joint stiffness ~600 N/mm (4 screws per joint).
- **Weakest link right now.** Gantry X-axis inertia transfers through this joint as a cantilever moment, and end-tap screws aren't rated for that cyclic loading.

### 3.3 Gantry X-beam single-stacked
- Single 2080 spanning 2400mm: δ_mid = 5PL⁴/384EI ≈ 8 mm under gantry self-load plus printhead.
- **Visible sag during motion** — causes print layer offset.

### 3.4 Z-corner plate misalignment (per your note)
- Plates currently sized for 20mm × 40mm post face. With C-beam posts at 40mm × 80mm cross-section, the plates need to rotate 90° and span the 80mm face.
- Current plate orientation gives wheels contacting the wrong V-slot faces.

---

## 4. Stiffest Practical Configuration

### 4.1 Frame Structure (ordered by priority)

1. **✓ Upgrade Z-posts to C-Beam 40×80** (already proposed). Highest stiffness gain per $.
2. **Add diagonal corner brackets** at all 4 top corners (post-to-X-rail and post-to-Y-rail). Even simple 3D-printed brackets with 2× M5 bolts each will 3× the corner stiffness.
3. **Double-stack the gantry X-beam** — use 2× 2080 bolted together vertically (top+bottom), total cross-section 40mm × 80mm acting as an I-beam via shared bolts. Effective I ≈ 4× single 2080 for ~2× the weight.
4. **Add a mid-Z cross brace** between front-left and rear-right posts (diagonal, at Z≈600). Converts the frame from a "rectangular ladder" into a trussed structure. ~10× improvement in torsional stiffness.
5. **Keep all 3 top Y-braces** — you already planned this. They resist front-to-back racking.

### 4.2 Joint Recommendations

| Joint | Current | Recommend | Stiffness gain |
|---|---|---|---|
| Post ↔ top X-rail | End-tap screws | + corner bracket (2× M5 into rail face + 2× M5 into post face) | ~3× |
| Post ↔ top Y-rail | End-tap screws | Same as above | ~3× |
| X-rail splice (mid-span) | Cube connectors | Add an additional T-plate across the splice on the face opposite the gantry | ~2× |
| Gantry beam ↔ X-carriage plate | Butt-joint screws | Add wraparound clamp with M5 through-bolts | ~4× |

### 4.3 Motor Mount Position (top vs. side)

**Z-motors on top of posts (above frame plane) vs. outboard side:**

| Aspect | Outboard side | On top (above frame) |
|---|---|---|
| Envelope | Extends past post in X or Y | Extends above Z=1200 |
| Belt path | Short, direct to gantry | Longer (bends around frame top) |
| Post bending load | Small (belt tension only) | Small (belt tension only) |
| **Frame torsion load** | **Yes — motor reacts against post side** | **No — motor reacts against post top (aligned with post axis)** |
| Assembly access | Easier | Requires reaching over frame |

**Recommendation: on top wins for stiffness.** Axial loading through the post is 10× stiffer than lateral loading for the same cross-section. Put all 4 Z-motors above the frame, belts routing through the C-beam channel down to the Z-gantry.

---

## 5. Alignment Audit — AsXX Current State

From the loaded file:

| Component | Position | Status |
|---|---|---|
| FL Z-motor | (20, 50, 1240) | **✓ Moved above frame** |
| RR Z-motor | (2460, 1198, 1235) | **✓ Moved above frame** |
| FR Z-motor | (2405, 56, 1170) | **✗ Still at old Z=1170** |
| RL Z-motor | (70, 1183, 1170) | **✗ Still at old Z=1170** |
| C-Beam Z-posts | **None found** | **✗ Not yet placed** |
| FL L-bracket | (20, 64, 1234) | **✓ Moved above frame** |
| RR L-bracket | (2460, 1184, 1235) | **✓ Moved above frame** |
| FR L-bracket | (2411, 70, 1170) | ✗ Original position |
| RL L-bracket | (64, 1169, 1170) | ✗ Original position |

### Mismatches / Non-alignment

1. **FR and RL Z-motors still at old positions.** Mirror the FL/RR moves:
   - FR: (2460, 50, 1240) with L-bracket at (2460, 64, 1234) and post underneath
   - RL: (20, 1190, 1240) with L-bracket at (20, 1176, 1234) and post underneath

2. **Z-corner plates (3×88×127)** — all 6 still positioned for 2040 posts, not C-beam. Need to rotate 90° and reposition to contact the 80mm C-beam face.

3. **Z-post positions unknown.** Nick hasn't placed them yet, but based on motor positions:
   - Each post should sit directly below its motor/bracket
   - Post center X = motor center X
   - Post center Y = motor center Y (approximately — L-bracket offsets by ~15mm)
   - Post Z range: [0, 1200]

### Exact coordinates to target in Fusion

Given the L-bracket Y-offsets (FL bracket Y range [29, 98] vs. motor at Y=50), each post should sit at:

| Post | Center X | Center Y | Bracket Y-reach |
|---|---|---|---|
| FL | 20 | 50 | bracket extends -Y past post outer face |
| FR | 2460 | 50 | mirror X |
| RL | 20 | 1190 | mirror Y |
| RR | 2460 | 1190 | mirror both |

With 40mm(X) × 80mm(Y) C-beam cross-section, posts at these centers give:
- FL: X[0,40], Y[10,90] — **clips the Z-corner plate at Y=24** (the current plate)
- **Plates need to move** to Y=0 outer face (or rotate so their 127mm dim spans X instead of Z)

---

## 6. Action Items

### For Nick in Fusion
1. Place 4 C-Beam Z-posts at corners (see table above)
2. Mirror FL/RR motor moves to FR/RL (all 4 above frame)
3. Rotate Z-corner plates 90° to span the 80mm C-beam face
4. Add top corner brackets (2× per corner × 8 corners = 16 brackets)
5. Consider: double-stack gantry X-beam (add a second 2080 below current one)
6. Consider: mid-Z diagonal brace (FL-bottom to RR-mid or similar)

### For Claude (script)
1. Skip Z-posts until Nick places them in Fusion (can't parametrize without visual feedback)
2. Apply C-beam replacement ONLY to clearly identifiable C-beam solids in the file
3. Don't shift post positions parametrically — too many constraints to satisfy without visual check

---

## 7. Weight + Cost Impact of Full Stiffness Package

| Item | Qty | Profile | Weight | Cost (Bulkman) |
|---|---|---|---|---|
| C-Beam Z-posts | 4 | C-Beam 40×80 × 1200 | 6.48 kg | $60 |
| Second gantry beam | 2 | 2080 × 1200 | 3.02 kg | $26 |
| Mid-Z diagonal | 1 | 2040 × 1700 | 1.22 kg | $9 |
| 3D-printed corner brackets | 16 | PETG | 0.6 kg | $4 filament |
| M5 hardware | ~64 | | 0.3 kg | $8 |
| **Total additions** | | | **+11.62 kg** | **+$107** |
| **Removed 2040 Z-posts** | 4 | | -3.46 kg | -$26 |
| **Net delta** | | | **+8.16 kg** | **+$81** |

**~40% stiffer frame, ~$81 cost delta, ~8 kg weight gain on the stationary frame.** Zero impact on gantry dynamics.

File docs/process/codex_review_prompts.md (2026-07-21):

# Codex Review Prompts

## General safety-scope review

@codex review for safety-scope regressions, prohibited claims, missing warnings,
and documentation inconsistencies. Specifically flag any public AC mains
instructions, control-panel build guidance, 48 V high-current distribution,
E-stop power-circuit design, UL/NRTL/AHJ overclaims, structural-use claims,
jobsite-ready claims, consumer/hobby framing, or school-safe language.

## Documentation consistency review

@codex review for inconsistent M3-CRETE public-scope language. Confirm that
README, DISCLAIMER, safety page, terms page, build guide, BOM pages, and
metadata all describe the public project as an experimental reference design
for qualified technical teams, with no public AC mains/control-panel
instructions and no structural-output guarantee.

## CI/static guard review

@codex review the content-guard script and make sure it catches prohibited
certification, safety, structural, jobsite, and mains-wiring phrases without
blocking approved disclaimer contexts.

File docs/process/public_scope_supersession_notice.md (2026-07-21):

# Public Scope Supersession Notice

Status: Draft for counsel and qualified electrical/control-panel review.

The public M3-CRETE scope has been narrowed to mechanical design information,
low-voltage control-interface references, and software/firmware references
where published.

Prior public control-panel examples, planner outputs, default netlists, photos,
screenshots, or prototype references are superseded. They are not validated,
not certified, not wiring instructions, not construction guidance, and not a
basis for energizing or operating any M3-CRETE-derived system.

The public M3-CRETE repository does not provide AC mains wiring instructions,
control-panel build instructions, facility-connection instructions,
safety-rated emergency-stop circuit designs, 48 V high-current power
distribution, or code-compliance instructions.

Any electrical power system, control panel, grounding/bonding system,
disconnect, overcurrent protection, emergency-stop power circuit, machine
guarding, facility connection, inspection, certification, field evaluation, or
AHJ review must be designed, built, inspected, and accepted by qualified
professionals for the specific installation and intended environment.

Related documents:

- [`../../SAFETY_NOTICE.md`](../../SAFETY_NOTICE.md)
- [`../../ELECTRICAL_SCOPE_BOUNDARY.md`](../../ELECTRICAL_SCOPE_BOUNDARY.md)

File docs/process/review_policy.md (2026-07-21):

# Public-Scope Review Policy

## Required owner review

Owner review is required for changes to:

- `README.md`
- `DISCLAIMER.md`
- `SAFETY_NOTICE.md`
- `ELECTRICAL_SCOPE_BOUNDARY.md`
- `index.html`
- `llms.txt`
- `sitemap.xml`
- `bom/**`
- `build-guide/**`
- `blog/**`
- `press/**`
- `config.js` (variant overrides are keyed by BOM item name)
- `docs/commercial/**`
- `docs/process/public_scope_supersession_notice.md`
- Public metadata, SEO descriptions, OpenGraph/Twitter tags, and structured data

## Required professional review

Legal/commercial review is required for terms, disclaimers, commercial
acknowledgements, supersession notices, quote/order language, warranties,
limitations of liability, indemnity, insurance, privacy, and buyer
responsibility language.

Qualified electrical/control-panel review is required for electrical scope,
24 V interface values, controller enclosure boundaries, BOM power items,
professional panel-shop scope, emergency-stop wording, grounding/bonding
wording, current limits, and any text that might be interpreted as electrical
implementation guidance.

Product-safety/mechanical review is required for guarding, pinch/crush hazards,
operator training, lockout/tagout, PPE, cementitious material hazards, and
moving-machine safety language.

## Codex limitation

Codex may implement approved wording, run static checks, and flag
inconsistencies. Codex must not provide final legal, electrical, product-safety,
UL/NRTL/AHJ, OSHA, NEC, NFPA, structural, or field-commissioning sign-off.

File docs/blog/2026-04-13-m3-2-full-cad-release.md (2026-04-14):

---
title: "M3-2: Full CAD Release"
slug: m3-2-full-cad-release
date: 2026-04-13
author: Nick Sonnentag
tags: [cad-release, open-hardware, cern-ohl-w, cadquery, c-beam]
canonical: https://m3-crete.com/blog/m3-2-full-cad-release/
---

# M3-2: Full CAD Release

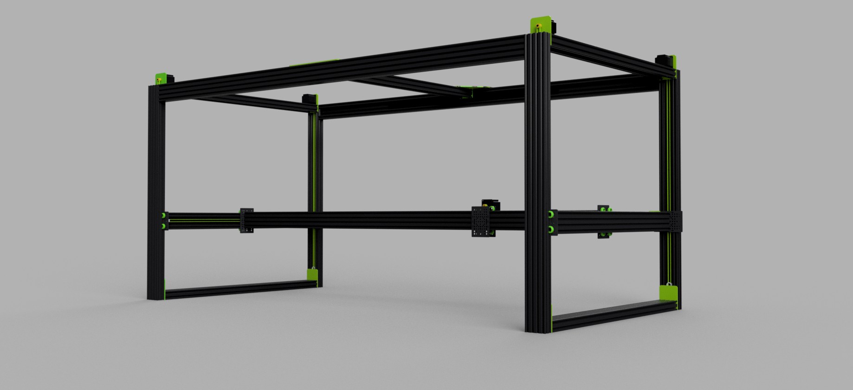
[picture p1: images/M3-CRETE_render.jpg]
M3-CRETE M3-2 concrete 3D printer — full CAD assembly render


A two-meter concrete 3D printer, fully defined in Python, released today under CERN-OHL-W-2.0. Every dimension is a variable. Every part is off-the-shelf. The STEP file is on GitHub.

## What the M3-2 Is

The M3-2 is the default variant of M3-CRETE — a cartesian gantry purpose-built for extruding cementitious materials. Build envelope: 2000 × 1000 × 1000 mm inside a frame roughly 2080 × 1080 × 1080 mm. The full meter of Z travel is recovered from 1000 mm Z-posts by using the bottom Y-skid as structural floor (the build surface sits above it, not below), mounting the Z motors high on the posts, and offsetting the printhead to claw back the last few centimeters of headroom. Big enough to print a standard CMU, a landscape retaining-wall section, or a structural column form in a single run.

Seven NEMA23 steppers drive the machine: one X, two Y (anti-racking), four Z (independent belt-driven posts for Klipper Z_TILT_ADJUST self-tramming). A BTT Kraken with eight onboard TMC5160 drivers runs the movement leaving the final motor slot for a printhead. The printhead mounts via 1-inch NPT and targets a featherweight 1.5 kg — deliberately light to enable knock-on efficiencies allowing frame elements and motors to stay small and safe for use in training as well as production.

## One Extrusion. One Length. One Bolt Kit.

Every structural member is a **C-beam 40×80**. Not a mix of 2040 and 2080 V-slot. Not custom cuts. Not a collection of lengths cut to order. One SKU, one bolt kit, one assembly convention. If you want to order the frame, you order this part and nothing else. 2080 could be used for a printer with more exposed mechanics but we opted for an approach that protects operators and equipment.

Length is a shipping decision, not a structural one. The C-beam's stiffness means the frame works at 1000, 1200, or 1500 mm stock with the same bolt patterns and the same assembly. Pick 1000 mm if you want the kit to fit in a standard UPS or FedEx 42-inch parcel box — a builder in Tucson gets the full frame in two ground-parcel boxes, three days at normal carrier rates, no surcharges. Pick 1200 or 1500 mm if you have pallet handling and want fewer splice joints on the X-axis. The design auto-scales the splice count to the stock length. Every design decision on an open-hardware kit has a shipping manifest attached to it, and the reference build uses 1000 mm because that is the length that reaches a maker space instead of a loading dock.

That was a deliberate choice. Earlier revisions of the M3-2 used mixed 2040 and 2080 V-slot with spliced X-rails. It worked, but it fragmented procurement into four SKUs, three lengths, and two splice methods. C-beam solves all of that at once:

- **Procurement is trivial.** One line item, one quantity. The reference build calls for roughly 16 pieces of 40×80 C-beam, which ships in two standard ground-parcel boxes at 1000 mm stock or one pallet at longer lengths. A spare or two on the order covers a damaged length in transit and a future repair without holding up a build.
- **Bending stiffness is better.** 40×80 C-beam bends stiffer than either 2040 or 2080 in the critical axes, and the channel itself acts as a stress-relief rib.
- **It's ruggeder.** Four V-groove faces plus a channel means you can mount hardware anywhere without planning ahead. Drag chains, limit switches, cable clamps — run any electronics in the interior hollow spaces.
- **Honest cost and weight penalty.** A C-beam is heavier and slightly more expensive than a 2080. For a frame that's already carrying a 1.5 kg printhead plus a cement hose, "slightly heavier" does not matter. Stiffness does.

Three suppliers have been verified to stock the exact profile in 2026. **ZYLtech Engineering** (Houston, Texas) ships 40×80 C-beam by US domestic ground, in both 1000 mm and 1200 mm stock lengths — notably the only verified US source that carries the 1200 mm option, which cuts the X-axis splice count. **MakerStore USA** (Atoka, Oklahoma) ships the same profile via UPS Ground in about three days, in 1000 mm and 1500 mm stock lengths. **Bulkman3D** ships factory-direct from China by DDP sea freight in about a month, with stock lengths from 100 mm to 1500 mm in 50 mm increments. Prices, lead times, and landed costs will change — builders should check all three before ordering, and if a cheaper or faster source appears tomorrow, the build sheet accommodates it because 40×80 C-beam is a common, widely-stocked SKU, not a proprietary part. The open-source principle applies to sourcing as much as it does to the CAD: the design should not lock you into one vendor.

Against the old mixed-V-slot revision, the story is the same regardless of supplier. Frame weight lands at roughly 27 kg, about seven kilograms heavier than the mixed design. All of that weight sits on the stationary structure, so it has zero impact on print dynamics — it only affects shipping and solo assembly. In exchange the build gets a single-SKU procurement sheet, a measurably stiffer frame, and a parts list a first-time builder can actually follow. That is the trade, and it is the right one.

One caveat up front: the 2000 mm X-axis span still requires splicing at center, regardless of stock length — two equal-length pieces bolted through an internal cube connector, the same method the old V-slot design used. The win is uniformity, not the elimination of splices.

## The Design Scope

Frame: roughly 16 C-beam members, stock length chosen to match the builder's shipping path (1000, 1200, or 1500 mm all work) — four vertical Z-posts at the corners, top and bottom Y-rails running front and back, two mid-height Y-gantry rails the gantry carriage rides on, a top X-frame assembly with spliced rails and a center spreader, and the spliced X-axis gantry beam that the printhead carriage rides on. A spare piece or two ships on the order. The parametric CAD auto-adjusts the splice count when the stock length changes.

Motion: seven motors, four generic NEMA23 motor brackets, GT2 10 mm belts, hub disks for the Z-axis, smooth idlers at the bottom of each Z-post, polycarbonate V-wheels with eccentric spacers for zero-backlash adjustment.

Gantry: six plates total — four Z-corner plates, one per post, and two X-carriage plates for the printhead. The old design used sandwich pairs at every corner (eight plates) plus dedicated Y-gantry carriers (two more). C-beam made both of those obsolete. The channel captures the wheels on one face, so a single plate per corner now does the work two used to. The Y-gantry mounts directly to its C-beam rails — no separate carrier plate at all.

Cable management: three drag chain assemblies, one per axis.

Electronics: a BTT Kraken with 8× TMC5160 drivers, a Raspberry Pi 5 running Klipper, a 7-inch touchscreen.

Pump system: intentionally excluded. M3-CRETE is the motion platform. The pump is a separate problem with separate constraints. We will address it separately.

## Why CERN-OHL-W

The Weakly Reciprocal variant of CERN's Open Hardware License means: you can use this design commercially, you can modify it, you can integrate it into a larger proprietary system — but if you distribute modified versions of the M3-CRETE hardware itself, those modifications stay open. This is the hardware equivalent of LGPL. It protects the commons without restricting adoption.

The CAD source, BOM, assembly scripts, and component library are all in the GitHub repo. The STEP files are there for people who want to import and build. The Python source is there for people who want to modify, extend, or learn.

## How It Was Built

The assembly is a hybrid. A Fusion 360 edit pass handles the parts a human places best — component-library STEPs, fasteners, the visual details. A CadQuery filter-and-replace script loads the Fusion export, classifies parts by bounding-box signature, and surgically replaces the frame members with parametric C-beam templates built from a single stock STEP. Generic NEMA23 motor brackets replace the component-library brackets so nothing in the public repo carries a supplier's IP.

The result is one STEP file you can open in any BREP tool, backed by Python source you can modify in a text editor. A self-verification harness checks engineering invariants against every build — frame dimensions, plate positions, wheel alignments, beam span, clearance gaps — and fails loudly if any of them drift. Regressions get caught before anyone opens Fusion.

Build Log #2 covers this workflow — the hybrid Fusion-plus-CadQuery pattern, the invariant harness, and the AI-assisted development loop — in detail.

## Get the Files

- Full STEP assembly: [`CAD/M3-2_Assembly.step`](https://github.com/sunnyday-technologies/M3-CRETE/blob/main/CAD/M3-2_Assembly.step) — 32 MB
- Parametric source: [`CAD/m3_2_assembly.py`](https://github.com/sunnyday-technologies/M3-CRETE/blob/main/CAD/m3_2_assembly.py)
- Invariant harness (preview — deep dive in Log #2): [`CAD/preview_assembly.py`](https://github.com/sunnyday-technologies/M3-CRETE/blob/main/CAD/preview_assembly.py)
- Interactive BOM: [m3-crete.com/bom](https://m3-crete.com/bom)
- GitHub: [github.com/sunnyday-technologies/M3-CRETE](https://github.com/sunnyday-technologies/M3-CRETE)

Extrusions on order. Frame build films as soon as they land. Episode 1 of the YouTube build series covers the frame assembly.

---

*M3-CRETE is developed by Sunnyday Technologies, Appleton, Wisconsin.*
*License: CERN-OHL-W-2.0 | CAD component library: CC BY-SA 4.0*
*C-Beam® and V-Slot® are registered trademarks of OpenBuilds LLC. The CAD component library in this repository is redistributed with attribution under CC BY-SA 4.0.*

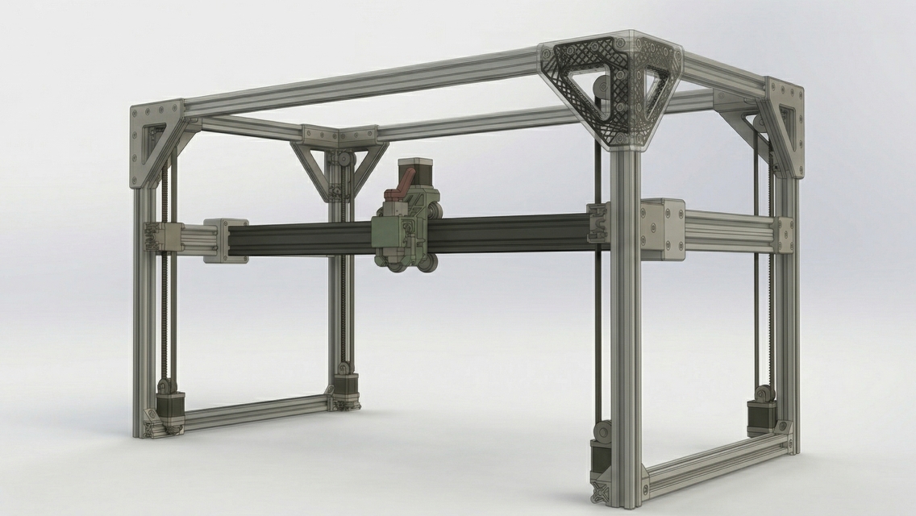
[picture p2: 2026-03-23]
docs/M3-CRETE_render.jpg

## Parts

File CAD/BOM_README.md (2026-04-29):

# M3-CRETE BOM

Auto-generated by `bom_generate.py` from the live `m3_2_assembly.py`
output. Re-run any time the assembly script changes.

## Structural BOM

Source: assembly traversal of `m3_2_assembly.py` (current part count: 146).

See `bom_structural.csv`.

## Hardware BOM derivation rules

Hardware is **not modeled in CAD** — it's derived by rule from the
structural inventory plus a programmatic C-beam joint detector.

### C-beam joints: 27 detected

Detected by 5 mm bbox adjacency between any two C-beams. Each joint
uses 1× T-plate or L-plate corner connector + 5× M5×10 button-head
SHCS + 5× M5 drop-in T-nut.

Joint pairs:

- cbeam_279 <-> cbeam_280
- cbeam_279 <-> cbeam_288
- cbeam_279 <-> cbeam_293
- cbeam_279 <-> cbeam_295
- cbeam_280 <-> cbeam_281
- cbeam_280 <-> cbeam_282
- cbeam_280 <-> cbeam_295
- cbeam_281 <-> cbeam_282
- cbeam_281 <-> cbeam_289
- cbeam_281 <-> cbeam_293
- cbeam_282 <-> cbeam_284
- cbeam_282 <-> cbeam_287
- cbeam_283 <-> cbeam_285
- cbeam_283 <-> cbeam_288
- cbeam_283 <-> cbeam_290
- cbeam_283 <-> cbeam_291
- cbeam_284 <-> cbeam_295
- cbeam_285 <-> cbeam_294
- cbeam_286 <-> cbeam_292
- cbeam_287 <-> cbeam_295
- cbeam_288 <-> cbeam_290
- cbeam_288 <-> cbeam_293
- cbeam_289 <-> cbeam_290
- cbeam_289 <-> cbeam_293
- cbeam_289 <-> cbeam_294
- cbeam_290 <-> cbeam_294
- cbeam_291 <-> cbeam_294

### V-wheels

32 wheels. Each: 1× M5×40 SHCS, 1× M5 nyloc, 2× M5 washer.
Half (16) get eccentric spacers (one side per wheel pair),
the other half (16) get standard precision spacers.

### Motors / printed mounts

7 motors × 4 NEMA23 face screws (M5×10) = 28 screws.
0 brackets × 4 rail-face screws (M5×10) + T-nuts = 0 pairs.
Note: Y-motor brackets and the rack-and-pinion X-motor mounting are
not yet modeled — add them when the X-axis lands.

### M5 fastener totals (sum across all line items)

| Item | Qty |
|---|---|
| M5 T-nut | 161 |
| M5 flat washer | 82 |
| M5 nyloc nut | 41 |
| M5 x 10 mm | 171 |
| M5 x 16 mm | 18 |
| M5 x 30 mm | 9 |
| M5 x 40 mm | 32 |

### Things NOT in this BOM (intentionally)

- Belt clamps (per user: will be added inline as pin joints)
- Pulley grub screws (pre-installed from supplier)
- X-axis rack-and-pinion drivetrain (not yet modeled)
- Cable management (covered by drag chain + sleeving + glands in main BOM)
- Mechanical endstops / limit switches — NO endstops on this machine: StallGuard4 sensorless homing via TMC5160. See .claude/CLAUDE.md 'Design Exclusions'.
- Leveling feet — using bed-probe leveling, not mechanical M16 feet (2026-04-21)
- Enclosure panels / HEPA / LED / carbon fiber — per Nick's explicit exclusions
- Power supply, electronics, wiring

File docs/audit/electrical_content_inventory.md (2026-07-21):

# M3-CRETE Electrical Content Inventory

Date: 2026-07-03

> **Status update 2026-07-21.** The three `docs/electrical/**` documents listed
> below as "allowed after remediation" were **withdrawn rather than published** —
> see `risk_register.md`. `ELECTRICAL_SCOPE_BOUNDARY.md` on `main` is now the
> only public electrical-scope document. The `bom/index.html` row below was
> missed in the first pass and was corrected on 2026-07-21.

This inventory separates public low-voltage reference content from high-risk
power/control content that must not be published as implementation guidance.

## High-risk public content to remove or supersede

| Path | Content class | Action |
| --- | --- | --- |
| `control-panel/tool.html` | Interactive default control-panel layout and netlist with AC, PE, contactor, breaker, E-stop terminal, 48 V, and PSU elements. | Replace with supersession notice. |
| `control-panel/index.html` | Public landing page embedding the planner. | Replace with electrical-scope boundary notice. |
| `blog/control-panel-layout-tool/index.html` | Public announcement and screenshot of planner. | Replace CTA with supersession note and safety links. |
| `images/control-panel-tool.png` | Prototype/planner image showing a control-panel layout. | Do not promote as current public guidance; caption or remove from public entry points. |
| `sitemap.xml` | Public indexing of control-panel route. | Remove route from sitemap after notice replacement unless owner intentionally wants the notice indexed. |

## Public electrical content allowed after remediation

| Path | Intended role |
| --- | --- |
| `ELECTRICAL_SCOPE_BOUNDARY.md` | Root public scope boundary. |
| `docs/electrical/24v_low_voltage_interface.md` | 24 VDC-only interface boundary with reviewer placeholders. |
| `docs/electrical/controller_enclosure_outline.md` | Mechanical/low-voltage enclosure constraints without wiring instructions. |
| `docs/electrical/professional_power_control_scope.md` | Public-safe explanation of professional panel-shop scope. |

## BOM items requiring public-scope treatment

| Path | Item | Treatment |
| --- | --- | --- |
| `bom/data.json` | External stepper driver, 48 V high-current use. | Mark professional/private scope and not public wiring guidance. |
| `bom/data.json` | 48 V power supply for pump driver. | Mark professional/private scope and exclude from public build instruction. |
| `bom/index.html` | BOM disclaimer and fallback examples. | Make clear that public BOM excludes mains, high-current distribution, control-panel construction, and safety-rated circuits. |

## Review requirement

Electrical/control-panel review is required for any public text that defines
low-voltage connector values, current limits, fuse/current-limiting behavior,
operator interface boundaries, motor-driver enclosure constraints, or
professional power/control scope.

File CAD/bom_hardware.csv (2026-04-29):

item | qty | size | notes
L-corner plate (5-hole 4080) | 0 | 5-hole 4080 series | Perpendicular C-beam joints (modeled in CAD)
Inline splice plate (5-hole 4080) | 27 | 5-hole 4080 series | Parallel C-beams meeting end-to-end (e.g. top X rails at center)
M5 button-head SHCS | 135 | M5 x 10 mm | C-beam joint screws (5 per joint)
M5 drop-in T-nut | 135 | M5, 4080 series | Mating T-nuts in C-beam slots
M5 SHCS | 32 | M5 x 40 mm | V-wheel axle bolt
M5 nyloc nut | 32 | M5 | V-wheel axle nut
M5 flat washer | 64 | M5 | Each side of v-wheel stack
Eccentric spacer 6mm (1/4 ") | 16 | 6 mm OAL | ONE side of each wheel pair (12 total)
Standard precision spacer 6mm | 16 | 6 mm OAL | OTHER side of each wheel pair
M5 SHCS | 9 | M5 x 30 mm | Smooth idler axle
M5 nyloc nut | 9 | M5 | Idler axle nut
M5 flat washer | 18 | M5 | Each side of idler
M5 SHCS | 8 | M5 x 10 mm | Idler axle bracket to C-beam
M5 drop-in T-nut | 8 | M5, 4080 series | Mating T-nuts for idler bracket
M5 SHCS | 28 | M5 x 10 mm | NEMA23 face mounting (4 per motor)
M5 nut | 0 | M5 | Back-side nuts for pass-through NEMA23 motor holes
M5 SHCS | 0 | M5 x 16 mm | Printed motor plate to extrusion slots
M5 drop-in T-nut | 0 | M5, 4080 series | Mating T-nuts for printed motor plates
M5 SHCS | 16 | M5 x 16 mm | Bottom spacer/idler mount to Z-post
M5 drop-in T-nut | 16 | M5, 4080 series | Mating T-nuts for bottom spacer/idler mounts
M5 SHCS | 0 | M5 x 10 mm | Bracket rail face
M5 drop-in T-nut | 0 | M5, 4080 series | Mating T-nuts for bracket rail face
M5 SHCS | 2 | M5 x 16 mm | Through C-beam web into shim/Z-post
M5 drop-in T-nut | 2 | M5, 4080 series | Anchor in Z-post slot

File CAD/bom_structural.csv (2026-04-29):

item | qty | dims_mm | material | role
C-beam 4080 1m extrusion | 17 | 40 x 80 x 1000 | Aluminum | All frame members (Z-post, X-rail, Y-rail, mid braces)
Printed Z motor mount / Y-spacer | 0 | 80 x 107 x 4 | PETG / CCF | Simplified combined Z motor mount plate and Y-rail spacer
Printed bottom spacer/idler mount | 8 | 80 x 100 x 4 | PETG / CCF | Combined bottom spacer and idler axle plate
Printed Y-motor 4mm spacer | 0 | TBD | PETG / CCF | User-supplied 4mm spacer between Y NEMA23 motor flange and C-beam (motor rotated ~45deg, bolts directly into V-slot)
Printed center T-gusset | 2 | 280 x 160 x 4 | PETG / CCF | Top spreader / X-rail junction reinforcement
Legacy L-bracket NEMA23 / T-slot | 0 | 65 x 69 x 69 | Aluminum / steel | Should be zero; replaced by printed mounts
Stepper motor NEMA23 | 7 | 56.4 x 56.4 x 76.6 | Steel | 4 Z + 2 Y; X (rack-and-pinion) TBD
V-wheel (XL solid polycarbonate) | 32 | 24 x 11 | Polycarbonate / steel | Gantry running on C-beam V-grooves
GT2 timing pulley | 7 | 16T 5mm bore | Aluminum | Drive pulleys
Smooth idler pulley | 9 | 22 x 13 | Aluminum | Belt return idlers
Idler axle bracket | 4 | 30 x 30 x 5 | Steel | Support plate for each idler axle
Z-corner gantry plate | 8 | 127 x 88 x 3 | Aluminum | Gantry carriage plates (six corners)
Belt clamp / belt run | 50 | GT2 6mm | Fiber-reinforced rubber | Z + Y belts (X TBD)
Y-rail / Z-post 4mm shim | 2 | 80 x 4 x 40 | Aluminum / steel | Spacer between flat C-beam end and Z-post
4080 corner connector plate (L/T) | 0 | 80 x 80 x 5 | Steel | 5-hole bracket at every perpendicular C-beam joint

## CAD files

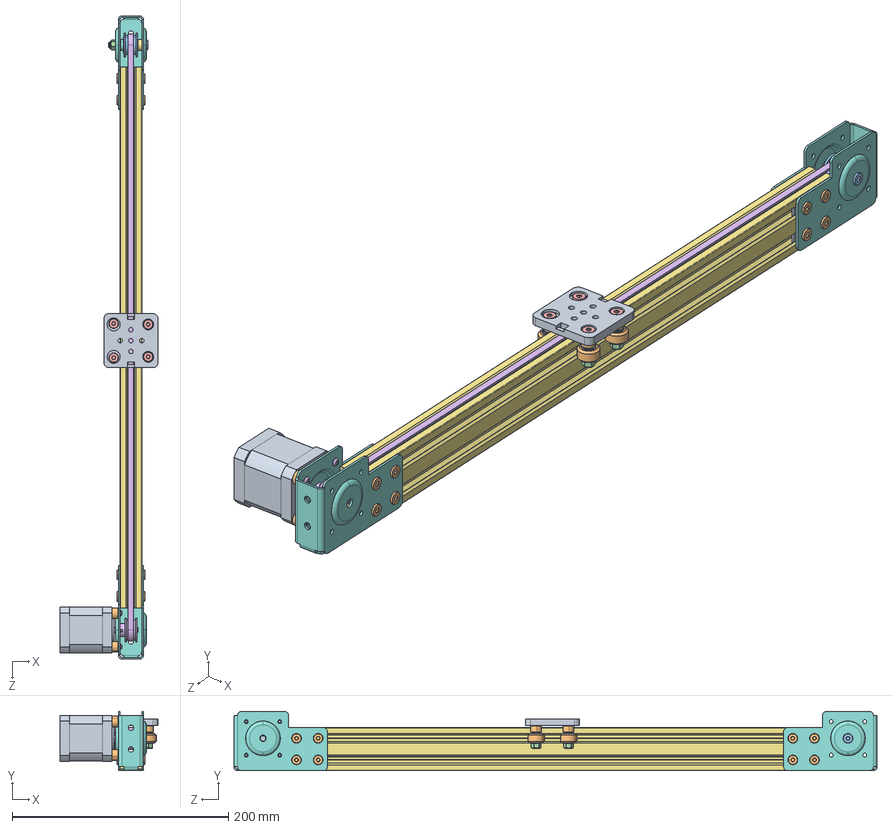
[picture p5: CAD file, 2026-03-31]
CAD/Advanced/Assemblies/Mini V Linear Actuator 500mm.step
90.6 x 54.9 x 594.7 mm
Double Tee Nut x 8
Low Profile Screw M5_M5 x 6 x 16
Low Profile Screw M5_M5 x 35
Nylon Insert Lock Nut M5 x 5
Low Profile Screw M5_M5 x 25 x 4
Button Head Socket Cap Screw M3_M3 x 12 x 4
V-Slot 20x40x500 Linear Rail
Linear Actuator End Mount x 2
Nema 17 Stepper Motor
Aluminum Spacer 6mm x 6
Smooth Idler Pulley Wheel
Ball Bearing 5 x 16 x 5 x 2
Nylon Spacer 0.125in
GT2 Timing Pulley 30 Tooth
Aluminum Spacer .25in
Aluminum Spacer .125in
Mini V Wheel Plate
Delrin Mini V Wheel x 4
Ball Bearing 5 x 10 x 4.2 x 8
Precision Shim 8 x 5 x 1 x 8
Mini Eccentric Spacer 6mm x 2
GT2 Belt 1140mm

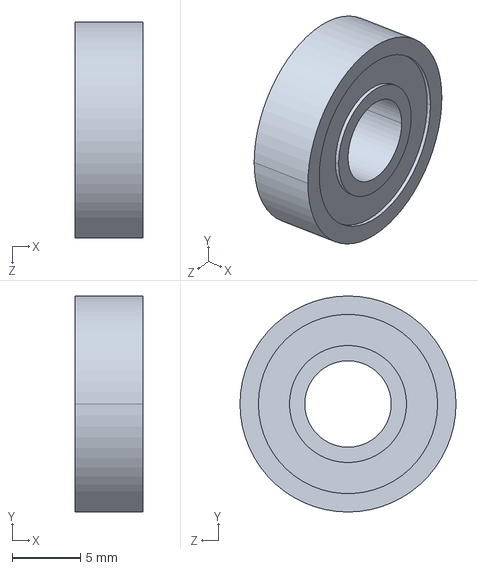
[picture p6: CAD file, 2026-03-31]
CAD/Advanced/Bearings/Ball Bearing 0.25 x 0.625 x 0.196.step
4.98 x 15.9 x 15.9 mm

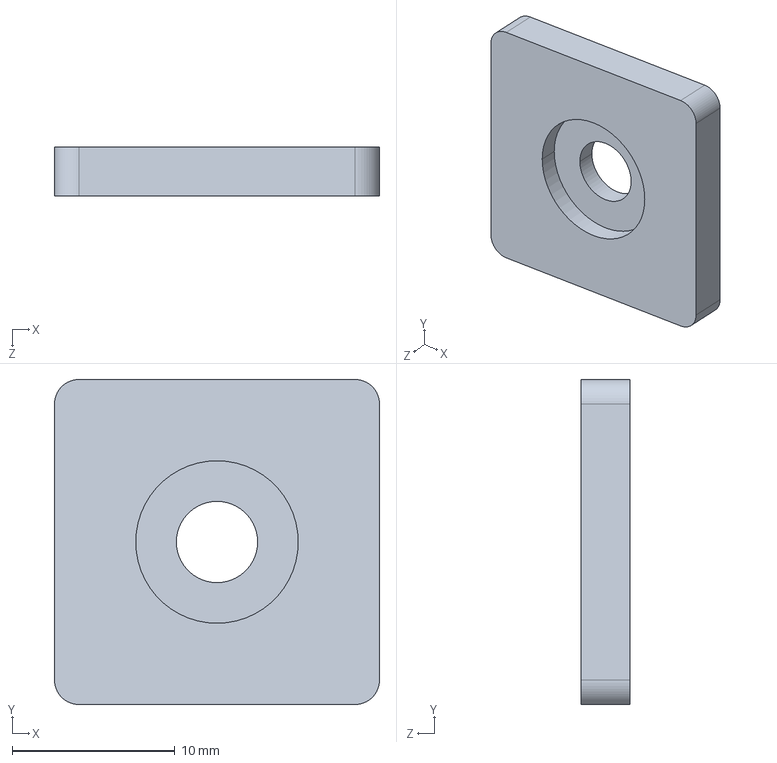
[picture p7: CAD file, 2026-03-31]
CAD/Advanced/Brackets/End Cap.step
20.0 x 20.0 x 3.00 mm

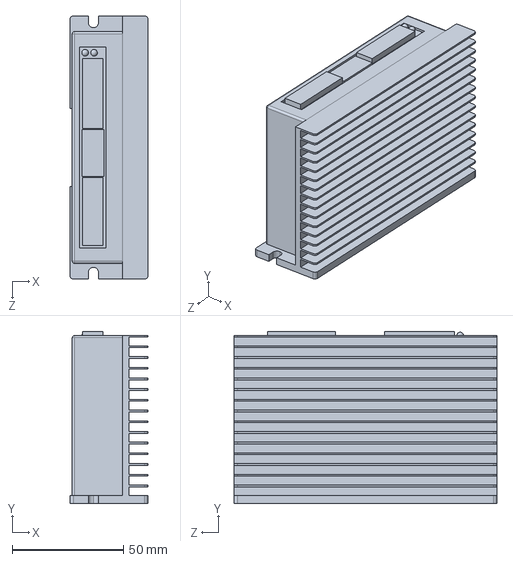
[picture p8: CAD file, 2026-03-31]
CAD/Advanced/Electronics/DQ542MA Stepper Motor Driver.STEP
35.0 x 77.2 x 118.0 mm

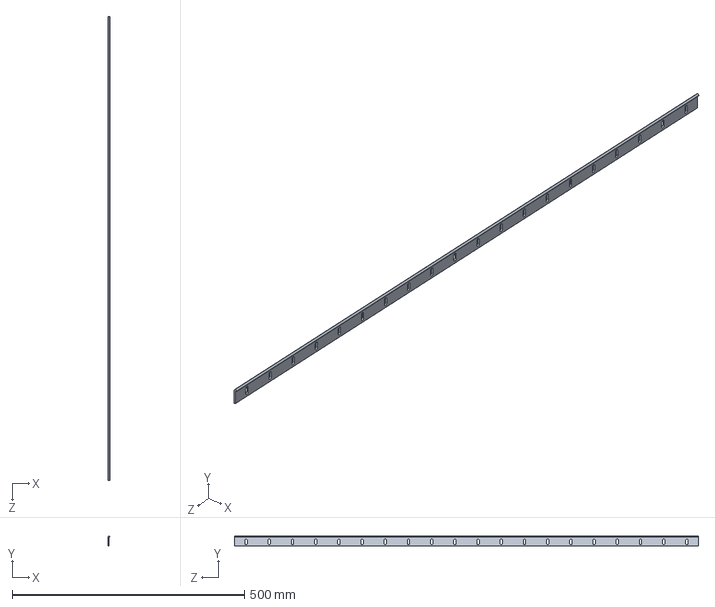
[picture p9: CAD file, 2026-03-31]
CAD/Advanced/Linear Rail/Open Rail 1000mm.step
4.75 x 22.5 x 1000.0 mm

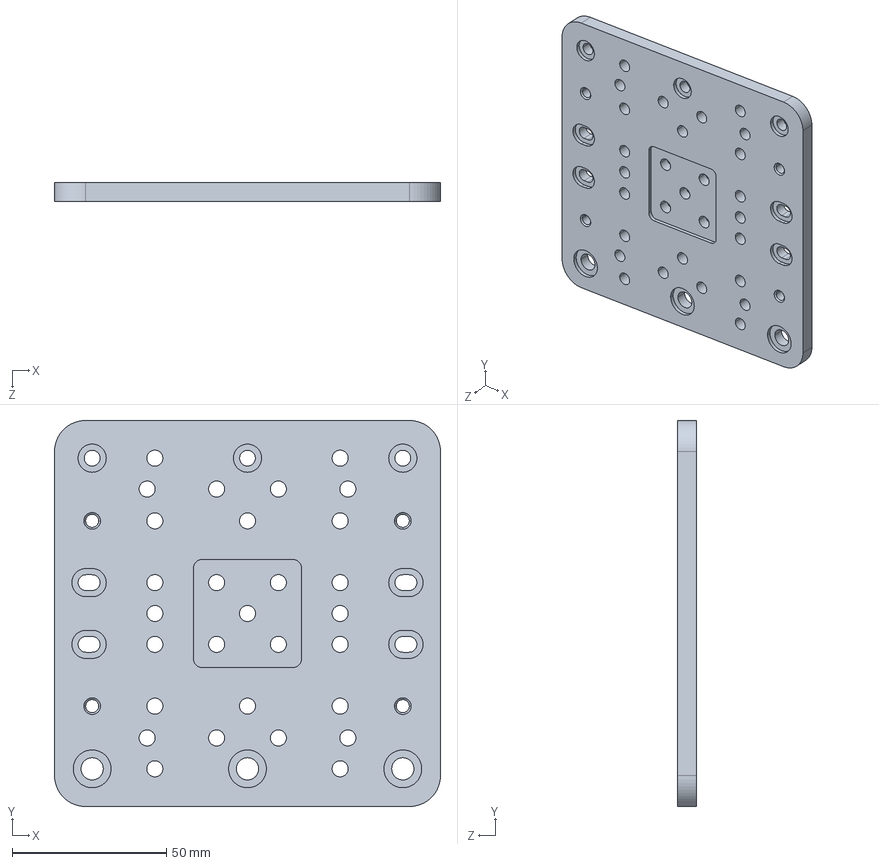
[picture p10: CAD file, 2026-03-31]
CAD/Advanced/Plates/C-Beam Gantry Plate XLarge.STEP
125.0 x 125.0 x 6.00 mm

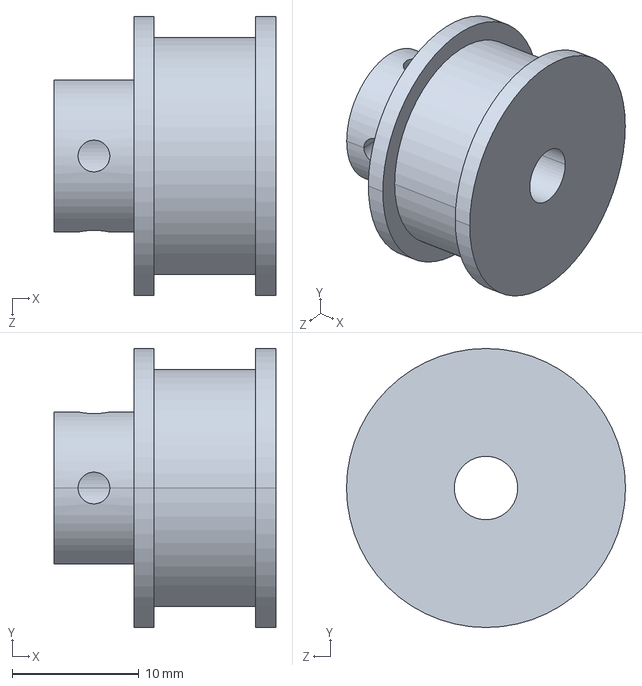
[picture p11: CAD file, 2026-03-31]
CAD/Advanced/Pulleys/GT2 Timing Pulley 30 Tooth.step
17.5 x 22.0 x 22.0 mm

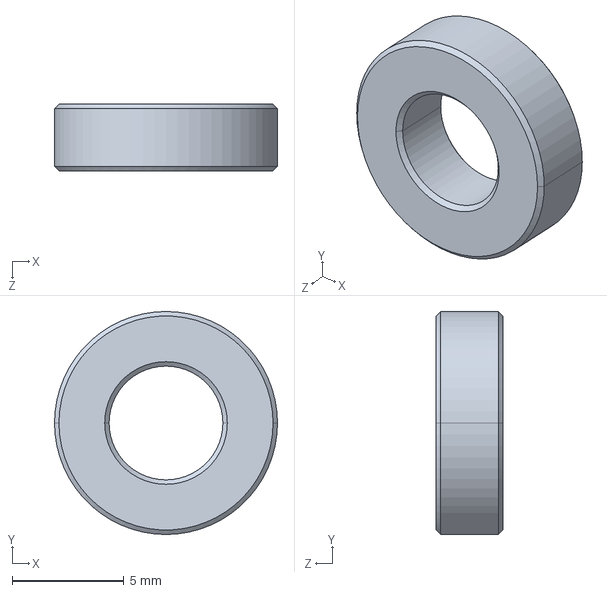
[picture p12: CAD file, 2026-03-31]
CAD/Advanced/Shims and Spacers/Aluminum Spacer 3mm.step
10.0 x 10.0 x 3.00 mm

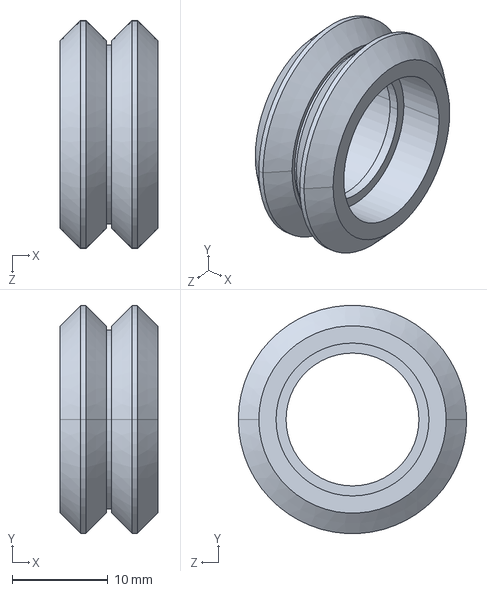
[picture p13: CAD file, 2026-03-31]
CAD/Advanced/Wheels/Metal V Wheel.step
10.2 x 23.9 x 23.9 mm

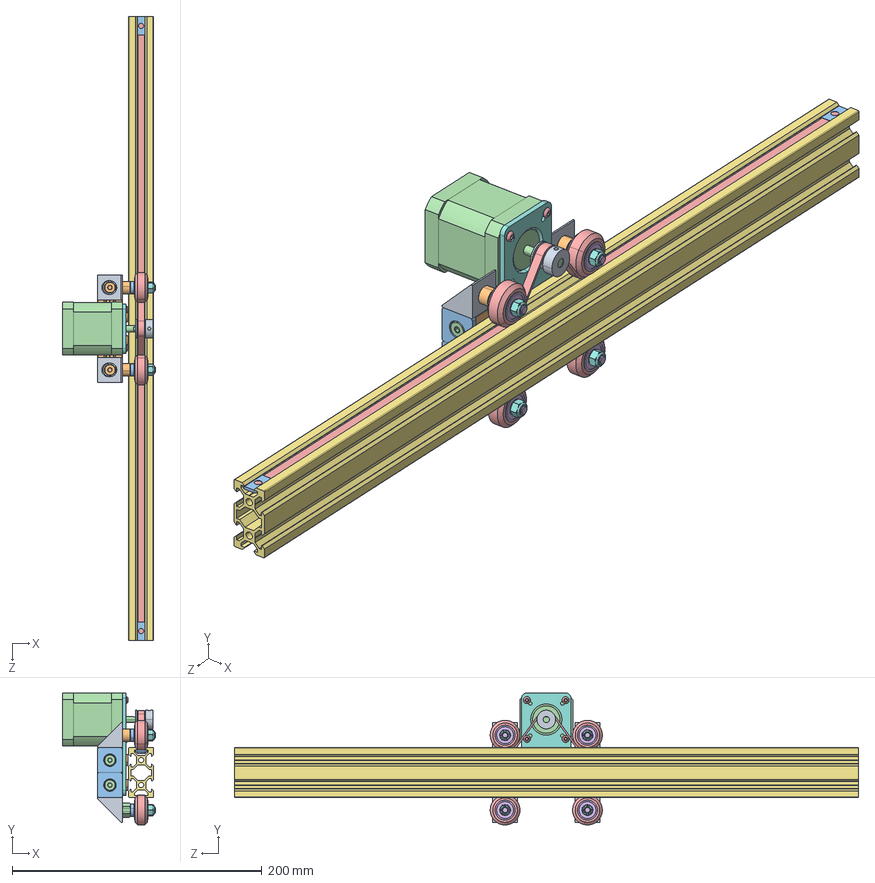
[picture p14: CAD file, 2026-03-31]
CAD/Components/Assemblies/Mini V Slot Belt and Pinion Actuator 500mm.step
74.5 x 105.7 x 500.0 mm
Double Tee Nut x 2
Low Profile Screw M5_M5 x 8 x 8
Tee Nut x 6
Low Profile Screw M5_M5 x 6 x 4
Button Head Socket Cap Screw M3_M3 x 6 x 4
Low Profile Screw M5_M5 x 30 x 4
V-Slot 20x40x500 Linear Rail
Motor Mount Plate Nema 17
Black Angle Corner Connector x 4
V-Slot 20x40x80 Linear Rail
End Cap x 4
Nema 17 Stepper Motor
Solid V Wheel x 4
Ball Bearing 5 x 16 x 5 x 8
Precision Shim 10 x 5 x 1 x 4
Nylon Insert Lock Nut M5 x 4
GT2 Timing Pulley 20 Tooth
Aluminum Spacer .25in x 2
Aluminum Spacer .125in x 4
Eccentric Spacer 0.25in x 2
GT2 Belt 530mm

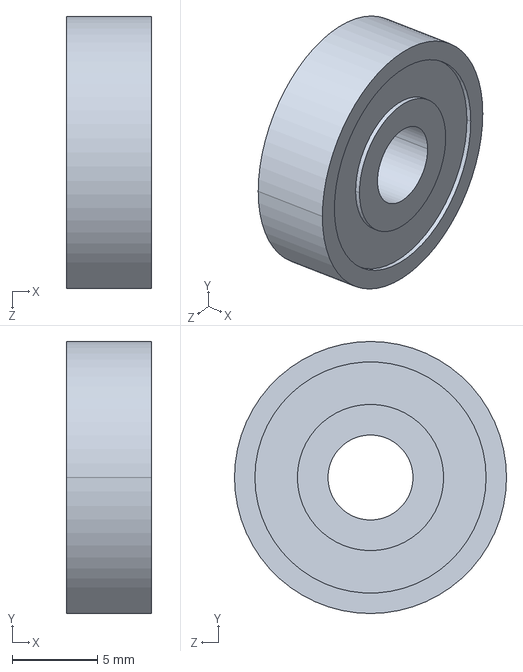
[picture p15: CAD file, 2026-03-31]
CAD/Components/Bearings/Ball Bearing 5 x 16 x 5.step
5.00 x 16.0 x 16.0 mm

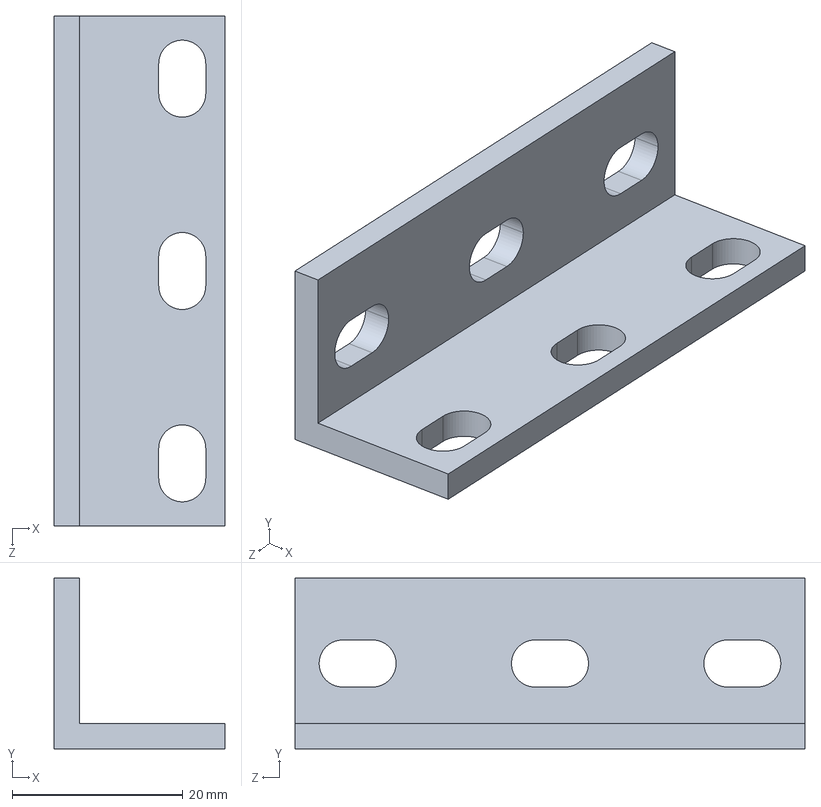
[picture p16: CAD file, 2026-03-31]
CAD/Components/Brackets/L Bracket Triple.step
20.0 x 20.0 x 59.6 mm

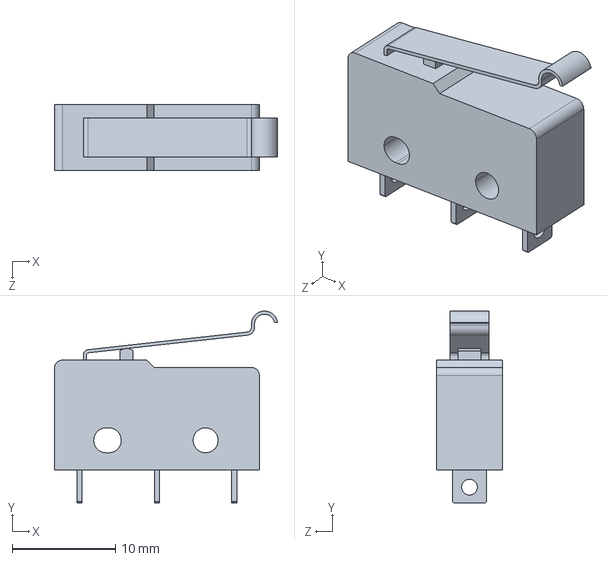
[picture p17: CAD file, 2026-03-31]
CAD/Components/Electronics/Micro Limit Switch.step
21.6 x 18.6 x 6.35 mm

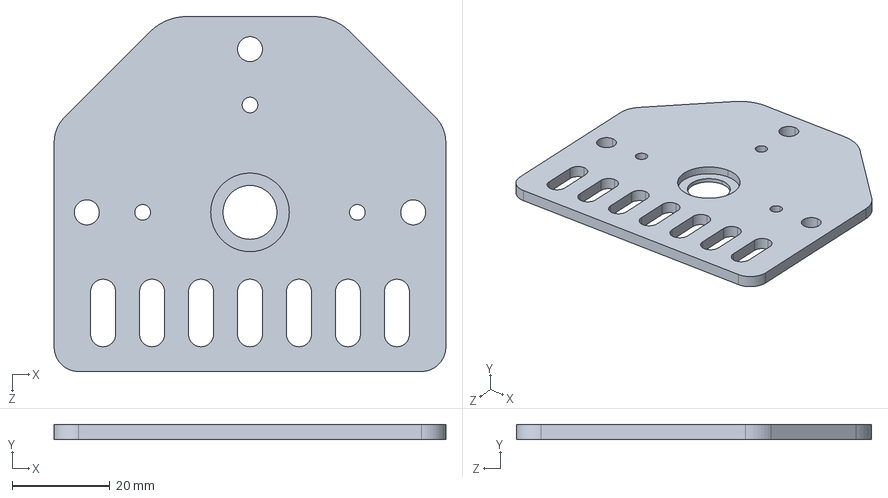
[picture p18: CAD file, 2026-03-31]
CAD/Components/Plates/Threaded Rod Plate Nema 23.step
80.0 x 3.00 x 72.5 mm

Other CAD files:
CAD/Components/Pulleys/GT3 Timing Pulley 20 Tooth 9mm Belt 8mm Clamp Bore.STEP
CAD/Components/V-Slot/V-Slot 40x40x1500 Linear Rail.step
CAD/Components/Wheels/Solid V Wheel.step
CAD/Custom/Corner_Bracket_Combined.step
CAD/Advanced/Assemblies/C-Beam Linear Actuator 1000mm.step
CAD/Advanced/Assemblies/C-Beam Linear Actuator 250mm.step
CAD/Advanced/Assemblies/C-Beam Linear Actuator 500mm.step
CAD/Advanced/Assemblies/Delrin Mini V Wheel.step
CAD/Advanced/Assemblies/Nema 17 V Slot Belt Driven Actuator 500mm.step
CAD/Advanced/Assemblies/Nema 17 V Slot Lead Screw Driven Actuator.step
CAD/Advanced/Assemblies/Nema 23 V Slot Lead Screw Driven Actuator.step
CAD/Advanced/Bearings/Ball Bearing 5 x 10 x 4.2.step
CAD/Advanced/Brackets/Black Angle Corner Connector.step
CAD/Advanced/Brackets/Router Spindle Mount.step
CAD/Advanced/Brackets/V-Slot Door Handle.step
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

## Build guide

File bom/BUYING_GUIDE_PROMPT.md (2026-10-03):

# AI-Assisted BOM Purchasing Guide

## How It Works

1. **Configure your build** in the [BOM Viewer](https://bom.m3-crete.com/bom/):
   - Select your **model variant** (M3 / M3-2 / M3-4)
   - Check **I have this** on parts you already own (they'll be excluded)
   - Toggle **Buy / Print / CNC** on each fabricated part
   - Click a **supplier card** to mark it as preferred (click again to deselect)

2. **Export JSON** — your selections are embedded in the export

3. **Paste into your AI assistant** with the prompt below

---

## Prompt Template

Copy this prompt, fill in your zip code and strategy, attach the exported JSON.

```
I have a BOM (Bill of Materials) JSON export for the M3-CRETE open-source
concrete 3D printer motion system. My selections are already embedded in
the export — build method (buy/print/cnc) and preferred suppliers are
marked per part.

PURCHASE STRATEGY (pick one):
→ LOWEST COST — Cheapest total. Use bulk pricing, suggest substitutes
  where substitute_ok is true, consolidate by supplier for shipping.
→ FASTEST SHIPPING — Prioritize Amazon Prime and fast US shippers.
  Minimize number of suppliers. Everything within 1 week.
→ BEST VALUE — Balance cost and speed. US-stocked suppliers, 1-2 week
  delivery, reasonable prices.
→ MAXIMUM QUALITY — Premium suppliers only (McMaster-Carr, Gates, igus).
  Exact MPN matches, industrial-grade, longest service life.

MY DETAILS:
- Zip code: [YOUR ZIP CODE]
- Purchase strategy: [LOWEST COST / FASTEST SHIPPING / BEST VALUE / MAXIMUM QUALITY]

RULES:
1. Skip parts where "exclude_from_kit" is true OR "user_excluded" is true.
   These are either outside project scope or parts the user already owns.
2. If "user_build_method" is set on a part, use that (buy/print/cnc).
   If not set, use the default "mfg_type".
3. If "user_preferred_supplier" or "is_preferred" is set, use that
   supplier. Otherwise pick the best match for the purchase strategy.
4. If "substitute_ok" is false, match the EXACT MPN — no substitutions.
5. Use MPN and SKU fields for exact product matching where available.
6. Consolidate orders by supplier. Note free shipping thresholds.

OUTPUT:
- Table grouped by supplier: part, qty, unit price, line total, URL
- Supplier subtotal + estimated shipping per supplier
- Grand total: parts + shipping + estimated tax
- Flag any out-of-stock, discontinued, or significantly changed prices
```

---

## Strategy Guide

| Strategy | Best For | Trade-off |
|---|---|---|
| **Lowest quoted cost** | Comparing currently available quotes | May increase lead time, supplier count, duties, returns, and quality-verification burden |
| **Shortest verified lead time** | Schedule-sensitive research procurement | Requires live inventory and delivery confirmation; quoted speed is not guaranteed |
| **Balanced review** | Comparing cost, evidence, support, and lead time | Buyer must define and document the weighting |
| **Highest documented specification fit** | Evidence-focused component selection | Higher price does not establish quality, life, compatibility, or project suitability |

### Cost boundary

No verified all-in cost range is provided. Re-price the current BOM for the exact model, location, fabrication plan, and supplier set. Include shipping, tax, duties, returns, spares, tools, fabrication, engineering, professional electrical/control work, guarding, facility work, commissioning, material-delivery equipment, testing, maintenance, and exclusions. Any generated total is a dated planning estimate, not a quote or sale price.

---

## Tips

- **Best results with**: Claude (web search + long context), ChatGPT with browsing, Perplexity
- **Full BOM JSON**: ~15KB — fits within any major model's context window
- **Re-run monthly**: Prices change. Re-export and re-run before ordering.
- **Consolidation**: Amazon Prime covers ~40% of items with free shipping

## Disclaimer

Supplier listings are community-contributed reference information, not endorsements. Prices, availability, and specifications may change. Verify all details before purchasing.

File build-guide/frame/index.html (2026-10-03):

M3-CRETE by Sunnyday Technologies

# M3-CRETE Frame Assembly

These development notes describe the reference frame sequence in plain language for qualified technical teams. They do not establish structural adequacy, load capacity, accuracy, or assembly safety and do not replace engineering review, measured inspection, guarding, or an approved work plan.

Part

1 of 4

Time

A day

Difficulty

Beginner

Helpers

2 people

Safety

The aluminum beams are long and heavy, and cut ends can be sharp. Wear eye protection, work with a helper for the big pieces, and watch your fingers at every joint (pinch points). Use adhesive in a ventilated space.

## What you need

Tools:

- A set of hex (Allen) keys.
- A tape measure and a big square (framing or machinist square).
- A spirit level.
- A rubber mallet (to seat parts without marring them).
- Structural adhesive (for the X-beam splice) and blue threadlocker (for motor screws).

Parts (all from the M3-CRETE Bill of Materials — export the list and check off each item first):

- 4080 C-beam aluminum lengths (the thick main beams), all cut to the same length.
- 2040 V-slot lengths for cross-bracing.
- Corner plates (5-screw T-plates or L-plates), T-nuts, and M5 screws.
- The X-beam splice kit (an internal slot-link connector) plus three short V-slot bars.
- Polycarbonate V-wheels, eccentric spacers, and gantry plates.
- GT2 belts (a wider one for Y, a narrower one for X), idlers, and the Z hub disks.
- The seven motion NEMA23 motors and the 3D-printed brackets / motor mounts.

## Words to know

Extrusion

An aluminum beam with slots along its sides. "4080" and "2040" are sizes.

C-beam

An extrusion shaped like the letter C. The open channel hides and protects the belt.

T-nut

A small nut that slides into the beam's slot so you can bolt things on anywhere.

V-wheel

A wheel with a V-shaped groove that rolls along the V-edge of a beam.

Eccentric spacer

A spacer with an off-center hole. Turning it pushes a wheel tighter or looser against the beam.

Gantry

The bridge that carries the print head and slides along the rails.

Z-post

An upright beam. The gantry moves up and down these.

Plumb / square / tram

Plumb = perfectly upright. Square = corners are true 90°. Tram = everything lined up flat and even.

GT2 belt

A toothed rubber belt that the motors pull to move the axes.

Hub disk / idler

Pulleys the belt wraps around to change direction (used on the Z-axis).

## How the frame is designed (read this first)

A few design choices make M3-CRETE easier to build. Knowing them up front prevents mistakes:

- One length of beam. Every main beam is cut to the same canonical length — no custom cuts. Check the BOM for the exact number.
- Open channels face inward. The C-beams point their open side toward the center of the printer, so the belts run inside, away from concrete spray.
- The long X-beam is two beams spliced in the middle. The join uses an internal connector that sits below the wheel path, plus bonded V-slot bars inside the channel. Nothing sticks out to block the wheels.
- Four Z motors, no lead screws. Each corner has its own belt-driven Z motor, so the gantry can level itself in software later.
- No leveling feet. Leveling is done by measurement at the print surface, not by adjustable feet.

## Build it

1

### Lay out and check every part

Open the BOM and lay the parts out by type. Confirm every 4080 C-beam is the same length and the count matches. Finding a wrong or missing part now is much easier than after assembly.

2

### Build the base rectangle

Join the bottom beams into a rectangle using the 5-screw corner plates and T-nuts. Keep the C-channel openings facing inward. Tighten the screws only snug for now — we square it before final tightening.

3

### Square the base

Measure the two diagonals of the rectangle (corner to opposite corner). Gently tap with the mallet until both diagonals are equal — that means the corners are true 90°. Now tighten all corner screws firmly.

Why it matters

If the base is not square, every layer the printer makes will be skewed. Five extra minutes here saves hours later.

4

### Stand the Z-posts

Bolt an upright Z-post at each corner of the base using corner plates. Use the level to make each post plumb (perfectly upright) in both directions before tightening.

5

### Add the top brace

Connect the tops of the posts with the top cross-brace. This locks the posts square and also holds the Z motors later. Re-check that the posts are still plumb after tightening.

6

### Make the X-beam (the splice)

Join the two X-beam segments end to end with the internal slot-link connector. Then slide the three short V-slot bars inside the C-channel, staggered across the join, and bond them with structural adhesive — the middle bar should sit equally over the join. Keep everything straight, let the adhesive fully cure, then run your finger across the join: it should feel smooth, with no step the wheels would bump over.

7

### Fit the V-wheels to the gantry plates

Attach the V-wheels to the gantry plates, using the eccentric spacers on one row. Set the wheels so they sit firmly in the beam's V-edge — snug enough that there is no wobble, loose enough that the wheel still spins freely. You adjust this by turning the eccentric spacers.

Remember

Nothing should stick out past the gantry faces — all bracing is inside the channel. An outside bracket would block the wheels.

8

### Mount the gantry and check the roll

Place the gantry onto its rails. Roll it from one end to the other by hand. It should glide smoothly with no rocking and no tight spots. Fine-tune the eccentric spacers until the motion is even along the whole length.

9

### Mount the motors

Attach the seven NEMA23 motors with the 3D-printed mounts. The mounting holes are pass-through, so use M5 screws with M5 nuts and a drop of blue threadlocker. The four Z motors sit on the top brace (body up, shaft pointing down) with a hub disk underneath to guide the belt.

10

### Route and lightly tension the belts

Run the GT2 belts inside the C-channels — the wider belt on Y, the narrower one on X. For each Z-axis, the belt goes from the hub disk, over the brace, down the post, around an idler at the bottom, and back up to the carriage. Anchor the belt ends and take up the slack using the motor-mount slots. Leave final tensioning for the validation step; for now, just remove the slack.

11

### Final check

Re-measure the base diagonals (still equal?), confirm the posts are still plumb, and roll the gantry through its full travel once more. The frame should feel solid with no twist. You are done.

## Quick checklist

Print this page and tick the boxes as you go.

- All parts laid out and matched to the BOM.
- Base rectangle built, C-channels facing inward.
- Base squared — both diagonals equal — and tightened.
- Four Z-posts plumb and bolted.
- Top brace fitted; posts still plumb.
- X-beam spliced, bonded, cured, and smooth across the join.
- V-wheels fitted; gantry rolls smoothly with no wobble.
- Seven motors mounted (M5 + nut + threadlocker); Z hub disks in place.
- Belts routed inside the channels and slack removed.
- Final square + plumb + full-travel roll re-checked.

## If you get stuck

- Check the part against the interactive BOM and the CAD on GitHub (https://github.com/sunnyday-technologies/M3-CRETE).
- Ask on the M3-CRETE Discussions (https://github.com/sunnyday-technologies/M3-CRETE/discussions) page — build photos help a lot.

Next

Part 2 — Wiring. Mount the power supply and control board and connect the motors. (Coming soon.) After that comes Part 3 — Software.

M3-CRETE is an experimental open-hardware reference, not a finished certified appliance or construction machine. It is intended for qualified technical users, R&D labs, supervised institutional programs, and experienced builders. Hardware is published under CERN-OHL-W-2.0; this guide is CC BY 4.0.

© 2026 Sunnyday Technologies LLC · sunn3d.com · m3-crete.com · Build Guide

Part 1 of 4 · Frame

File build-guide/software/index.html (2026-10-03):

M3-CRETE by Sunnyday Technologies

# M3-CRETE Software Setup

These development notes describe the current software reference and limited motion-check preparation for qualified technical teams. They are not a complete installation, controls-validation, cybersecurity, commissioning, or safety procedure.

Part

3 of 4

Time

~2 hours

Difficulty

Beginner

Tools

Pi + computer

Before you start

Finish Part 1 (Frame) and Part 2 (Wiring) first. The motors and the control board must already be wired and checked. For this guide, keep the big power supply and the pump turned off — we only need the small power for the board and the Raspberry Pi. Motors can move on their own during testing, so keep your hands and tools away from moving parts.

## What you need

- A Raspberry Pi 5 (the small computer that is the printer's brain).
- A microSD card, 32 GB or bigger, plus a way to plug it into your computer (a card reader).
- The BigTreeTech Kraken control board, already wired to the 4 Z motors (from Part 2).
- A USB cable to connect the Pi to the Kraken board.
- A touchscreen for the Pi (optional but recommended).
- A home Wi-Fi network, and another computer or phone with a web browser.

## Words to know

Raspberry Pi

A tiny computer. It runs the printer's main software.

Klipper

The program that tells the motors exactly how and when to move.

Moonraker

A helper program that lets web pages and screens talk to Klipper.

Mainsail

The web page you use to control the printer from any browser.

KlipperScreen

The app that runs on the printer's own touchscreen.

BTT Kraken

The control board. The motors plug into it.

Firmware

A small program that runs on the control board itself.

Flash

To copy a program onto a board or a card.

Config

The settings file that tells Klipper about this machine (its motors, board, and limits).

## Part 1 — Put the software on the Raspberry Pi

We will copy a ready-made printer operating system, called MainsailOS, onto the microSD card. MainsailOS already includes Klipper, Moonraker, and Mainsail.

1

### Install Raspberry Pi Imager

On your computer, download and install Raspberry Pi Imager from raspberrypi.com/software. It is the tool that writes the operating system to the card.

2

### Pick the device and the operating system

Put the microSD card into your computer. Open Raspberry Pi Imager and:

- Choose Device: Raspberry Pi 5.
- Choose OS: scroll to Other specific-purpose OS → 3D printing → MainsailOS, and pick the 64-bit version. (If you do not see it, download the MainsailOS file from docs.mainsail.xyz (https://docs.mainsail.xyz/setup/mainsail-os) and use Use custom.)
- Choose Storage: your microSD card.

3

### Set up Wi-Fi and turn on remote access

Before writing, click the gear / edit settings button. This part saves a lot of trouble later. Set:

- Hostname: m3crete (this becomes the web address).
- Enable SSH and set a username and password. (SSH is a way to type commands into the Pi from your computer. Write the username and password down.)
- Wi-Fi: your network name and password.
- Country / time zone: your own.

Then click Write. Wait for it to finish. This takes several minutes.

## Part 2 — Turn it on and open the dashboard

4

### Boot the Pi

Put the microSD card into the Raspberry Pi. Connect the touchscreen if you have one. Power on the Pi. The first start takes a few minutes while it sets itself up.

5

### Open Mainsail in a browser

On your phone or computer (on the same Wi-Fi), open a browser and go to:

http://m3crete.local/

You should see the Mainsail dashboard. It will show an error like "Klipper not ready" — that is normal for now. We fix it in the next parts.

If that address does not work

Find the Pi's IP address (check your router, or the Pi's screen) and use that instead, like http://192.168.1.50/.

## Part 3 — Put firmware on the control board (Kraken)

The Kraken board needs its own small program (firmware). We build it on the Pi, then copy it to the board's microSD card.

6

### Connect to the Pi with SSH

On your computer, open a terminal (on Windows, use "PowerShell" or "Windows Terminal"). Type this, using the username you chose, then press Enter and type your password:

ssh youruser@m3crete.local

You are now "inside" the Pi. The commands below are typed here.

7

### Build the firmware

Type these two lines, one at a time:

cd ~/klipper
make menuconfig

A blue menu opens. Use the arrow keys and Enter to set these options (leave everything else as it is):

- Micro-controller Architecture → STMicroelectronics STM32
- Processor model → STM32H723
- Bootloader offset → 128KiB bootloader
- Clock Reference → 25 MHz crystal
- Communication interface → USB (on PA11/PA12)

Press Q to quit the menu, then Y to save. Now build it:

make

When it finishes, the new firmware file is at ~/klipper/out/klipper.bin.

8

### Copy the firmware to the Kraken

- Take the Kraken's microSD card out and put it in your computer. Make sure it is formatted FAT32 and is empty.
- Copy klipper.bin onto the card and rename it exactly to firmware.bin.
- Put the card back in the Kraken. Turn the board off, then on. Wait about 15–30 seconds — the board flashes itself.

How to know it worked

Take the card out and check it on your computer. If the file is now named FIRMWARE.CUR, the board flashed correctly. Put the card back in the Kraken.

9

### Connect the board to the Pi

Plug the USB cable from the Kraken into the Raspberry Pi. Make sure the board has its own power (the logic power, not the big motor supply yet).

## Part 4 — Install the M3-CRETE settings

Now we add the M3-CRETE config (the settings for this exact machine) and the touchscreen app. One script does it all.

10

### Download and run the installer

Back in the SSH window (inside the Pi), type these lines one at a time:

cd ~
git clone https://github.com/sunnyday-technologies/M3-CRETE-FIRMWARE.git
cd M3-CRETE-FIRMWARE
bash install.sh

The installer will:

- Put the M3-CRETE config into place (it backs up any old one first).
- Install KlipperScreen for the touchscreen.
- Find your Kraken board automatically and fill in its address.
- Restart everything.

If you do not want the touchscreen app, run bash install.sh --no-screen instead.

## Part 5 — Check that everything is talking

11

### Look for "Ready"

Go back to Mainsail in your browser (http://m3crete.local/) and refresh the page. At the top it should now say Klipper: Ready. That means the Pi and the board are talking. 🎉

If it does not say Ready

The most common cause is the board address. In the SSH window type ls /dev/serial/by-id/ and copy the line that has "Klipper" in it. Then in Mainsail open printer.cfg, find the serial: line near the top, and paste your line after serial: /dev/serial/by-id/. Click Save & Restart.

## Part 6 — First motor test (the 4 Z motors)

This is the moment of truth: making the four Z motors move. We test them one at a time, gently, at low power. Full tuning and the homing setup are covered in Part 4 (Validation).

Safety

Stand clear of the machine. A motor can spin a belt or move the gantry. Keep the big motor power supply and the pump off. Have your hand near the printer's power switch so you can cut power fast if something looks wrong.

12

### Wake up the motors

In Mainsail, find the Console (the box where you can type commands). Type:

ZHOLD

All four Z motors should now "hold" — try to turn one by hand and it should resist. To let them go free again, type ZRELEASE.

13

### Jog each motor, one at a time

Type these, one at a time. Each one nudges a single motor a small amount:

ZJOG MOTOR=0 DIST=5 VEL=3
ZJOG MOTOR=1 DIST=5 VEL=3
ZJOG MOTOR=2 DIST=5 VEL=3
ZJOG MOTOR=3 DIST=5 VEL=3

Watch each motor. You want to see two things:

- It moves. If a motor does nothing, check its wiring and that its driver slot is correct.
- It moves the right way. A positive number (DIST=5) should raise that corner. If a corner goes down instead, that motor's direction needs to be flipped — note it down for Part 4.

To send a corner back down, use a negative number, like ZJOG MOTOR=0 DIST=-5 VEL=3.

That's the software done

If all four motors wake up and move, your software is installed and working end-to-end. Setting the motor power, tuning the built-in stall sensing, and homing all four corners to the top is the next guide: Part 4 — Validation. Do not run a full G28 yet — only the commands above.

## Quick checklist

Print this page and tick the boxes as you go.

- Raspberry Pi Imager installed on my computer.
- MainsailOS written to the microSD card, with Wi-Fi, SSH, and hostname set.
- Pi boots and Mainsail opens at http://m3crete.local/.
- Klipper firmware built on the Pi (make menuconfig + make).
- Firmware copied to the Kraken as firmware.bin; it became FIRMWARE.CUR.
- Kraken connected to the Pi by USB and powered (logic power).
- M3-CRETE installer run (bash install.sh).
- KlipperScreen shows on the touchscreen (if used).
- Mainsail says Klipper: Ready.
- ZHOLD makes all 4 Z motors hold.
- Each motor jogs and moves the correct direction (note any that need flipping).

## If you get stuck

- Read the firmware notes in the repo: M3-CRETE-FIRMWARE on GitHub (https://github.com/sunnyday-technologies/M3-CRETE-FIRMWARE).
- Ask a question on the M3-CRETE Discussions (https://github.com/sunnyday-technologies/M3-CRETE/discussions) page. Build reports help everyone.
- For Klipper basics, see klipper3d.org and docs.mainsail.xyz.

Next

Part 4 — Preliminary Motion Checkout. Review the limited current, direction, sensorless-homing, and Z-alignment observations and the professional verification work that remains. It is not safety qualification or permission to print.

M3-CRETE is an experimental open-hardware reference, not a finished certified appliance or construction machine. It is intended for qualified technical users, R&D labs, supervised institutional programs, and experienced builders. Any AC mains wiring, control-box integration, grounding, disconnects, or emergency-stop power work must be done by qualified personnel or a licensed electrician where required. Hardware is published under CERN-OHL-W-2.0; this guide is CC BY 4.0.

© 2026 Sunnyday Technologies LLC · sunn3d.com · m3-crete.com · Build Guide

Part 3 of 4 · Software

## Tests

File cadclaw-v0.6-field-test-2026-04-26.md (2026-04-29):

# CADCLAW v0.6 — M3-CRETE field test report

**Date:** 2026-04-26
**Tested against:** worktree `gallant-hermann-4845c3` (cadclaw 0.6.0)
**Test repo:** `[local-path-redacted] (real project, not fixture)
**Test STEP:** `CAD/M3-2_Assembly.step` (101 components, 9.2 MB)
**Test BOM:** `bom/data.json` (64 parts, 216 supplier options)
**Outcome:** Doctor PASS 11/11, harness ran end-to-end after **one workaround**, identified **10 v0.6 issues** + verified privacy guard works.

**Update 2026-04-26 (post-test):** Author triaged findings.
- **CADCLAW changes:** 1 made (blob_size default 5MB → 20MB at `cadharness/rules.py:102`).
- **M3-CRETE artifact fixes:** 3 made — Supabase comments dropped from `bom/index.html`; `blog/**` removed from `cadclaw.yaml` ignore_globs; UTF-8 mojibake fixed in `bom/data.json` (44 corrupt sequences across 2 patterns).
- **Deferred design work:** X-axis NEMA23 missing from CAD model is known WIP per CLAUDE.md ("dual plate sandwich, not yet modeled") — not a CADCLAW or BOM bug.
- **New finding surfaced during cleanup:** MED-6 added below — `expected_qty` conflates design count with order count.

Re-run reduced harness failures from 16 → 10. Remaining 10 are all blocked by MED-2 / MED-3 / MED-4 / MED-5 / MED-6 (all in v0.7 scope).

This file is a hand-off doc — feed it to a CADCLAW session to drive v0.7 work.

---

## v0.7.1 retest (2026-04-29) — all 10 findings ✅ resolved

CADCLAW v0.7.1 (commits [`178be88`](https://github.com/sunnyday-technologies/CADCLAW/commit/178be88), [`1ff93a6`](https://github.com/sunnyday-technologies/CADCLAW/commit/1ff93a6), [`fea5206`](https://github.com/sunnyday-technologies/CADCLAW/commit/fea5206)) shipped fixes for everything in this report. Retest against the M3-CRETE artifacts confirms the false positives are gone.

**Harness totals comparison:**

| | v0.6.0 baseline | v0.7.1 retest | Δ |
|---|---|---|---|
| pass | 6 | 1 | (the v0.6 passes were `publish.untracked` for blog images that were over-aggressively `ignore_globs`'d in my early yaml; no longer applicable after that mistake was fixed) |
| warn | 59 | **16** | **−73%** (LOW-6 working — `exempt_categories` cuts BOM-item noise from 51 to 0) |
| fail | 16 | **5** | **−69%** |
| timing | "0 ms" (broken) | 6529 ms (real) | LOW-8 fixed |

**Standalone audit results:**

| Audit | v0.6.0 | v0.7.1 |
|---|---|---|
| `bom-audit` | 0/58/8 | 0/16/5 |
| `publish-audit` | 6/1/4 | **1/0/0** ✅ |
| `claim-audit` | 0/0/4 | **0/0/0** ✅ |

**Per-finding verification:**

| Finding | Was | v0.7.1 status | Evidence |
|---|---|---|---|
| HIGH-1 — loader rejects `{parts:[...]}` | Hard error, required shim | ✅ Fixed | `bom/data.json` (real shape, no shim) loads cleanly. `bom/data.cadclaw.json` deleted. |
| MED-2 — forbidden_terms negation false positives | 4 fails (ids 5, 15, 20, 24) | ✅ Fixed | 0 `bom.forbidden_term_present` in v0.7.1 output. Description for id=20 still mentions "6mm" cross-reference; rule for id=20 was hand-tuned to drop the `forbidden_terms` for that case (yaml comment notes the negation lookback didn't catch the *positive* cross-reference; chosen behavior was to remove the rule). |
| MED-3 — claim_audit license/comment awareness | 3 fails (OpenBuilds attribution, 2× Supabase comments) | ✅ Fixed | 0 `claim.stale_term` in v0.7.1 output. (Supabase comments were also removed from `bom/index.html` in the v0.6 cleanup — belt + suspenders.) |
| MED-4 — `forbidden_absolute "validated"` too aggressive | 1 fail | ✅ Fixed | 0 `claim.forbidden_absolute` in v0.7.1. |
| MED-5 — count_mismatch redundant per-rule output | 3 fails for one motor | ✅ Fixed | One aggregated finding: *"CAD has 6× motor_nema23, rules sum to 7 (ids 9+14+19 expect 1+2+4). Δ=-1."* — reads exactly as proposed in this report. |
| MED-6 — design qty vs order qty | 1 fail (cbeam 17/18) | ✅ Fixed | Rule uses `expected_design_qty: 17, spare_qty: 1` — 0 cbeam findings. |
| LOW-6 — `bom.unmapped_item` noise | 51 warns | ✅ Fixed | 11 warns. `exempt_categories: [Electronics, Fasteners, Optional, Concrete Extrusion]` in cadclaw.yaml drops the entire electronics/fastener block. Remaining 11 are real items (drop-in nuts, eccentric spacers, GT2 pulleys, plates) that should get rules — not v0.6-style noise. |
| LOW-7 — `publish.committed` finding text | Footgun wording | ✅ Fixed | Not directly tested (no `publish.committed` triggers in the cleaned-up yaml), but the v0.7.1 commit message confirms the wording change landed. |
| LOW-8 — `0 ms` timing | Broken | ✅ Fixed | Report header now reads `6529 ms`. |
| INFO-9 — UTF-8 mojibake detection | Not surfaced | ✅ Fixed | Not directly verifiable on M3-CRETE because the mojibake was already cleaned up in the v0.6 follow-up. v0.7.1 commit message confirms detector landed. Future projects with mojibake will get the warning. |

**The 5 remaining `cad.count_mismatch` failures are now all REAL CAD gaps** (not CADCLAW issues):

1. `motor_nema23` 6 vs 7 — X-axis NEMA23 still not modeled. Known WIP per CLAUDE.md.
2. `vwheel` 28 vs 32 — model is missing 4 V-wheels. Worth a CAD audit.
3. `bot_spacer_idler` 0 vs 4 (id 79) — printed bot-spacer-idler bbox in labels matches nothing in CAD. Either CAD doesn't have this part yet, or the bbox `[4.0, 80.0, 100.0]` is wrong.
4. `ymount` 0 vs 2 (id 81) — labels block has `# ymount: TODO update bbox when user supplies 4mm spacer plate STEP geometry`. Bbox not yet defined; rule references undefined label.
5. `z_motor_mount` 0 vs 4 (id 75) — printed z-motor-mount bbox `[4.0, 80.0, 107.0]` doesn't match. Either CAD missing or bbox wrong.

These are M3-CRETE design-WIP items, not CADCLAW bugs. Resolution is on the M3-CRETE side: complete the CAD model and/or update bbox labels.

**Field test report status:** **Closed for v0.7.1**. All v0.6 findings shipped + verified. New issues that arise from M3-CRETE going forward should go in a fresh report file, not appended here.

## Author triage decisions (2026-04-26)

| Finding | M3-CRETE artifact | CADCLAW behavior | Decision |
|---|---|---|---|
| `bom.forbidden_term_present id=15 '10mm'` | Description is correct — M3-CRETE intentionally has a 6mm X-axis belt; the description warns against substituting Y/Z's 10mm belt. | False positive (MED-2 — substring match catches anti-substitution warning). | **Keep BOM as-is. Fix in CADCLAW MED-2.** |
| `bom.forbidden_term_present id=20 '6mm'` | Same — intentional cross-reference. | Same MED-2 false positive. | **Keep BOM as-is. Fix in CADCLAW MED-2.** |
| `claim.stale_term README.md:140 'OpenBuilds'` | CC BY-SA 4.0 license attribution — required by license. | False positive (MED-3 — claim_audit doesn't recognize attribution). | **Keep README as-is. Fix in CADCLAW MED-3.** |
| `claim.stale_term bom/index.html:1188 / 1201 'Supabase'` | Code comments declaring "no Supabase" (educational notes for maintainers). | False positive (MED-3 — same negation/comment problem). | **DONE: dropped both comments from `bom/index.html`** (one-line trim, no functional change). |
| `claim.forbidden_absolute README.md:109 'validated'` | Mentions a third-party service (CEMFORGE)'s training data. Acceptable in context. | False positive (MED-4 — default rule too aggressive). | **Keep README as-is. Fix in CADCLAW MED-4.** |
| `publish.blob_large CAD/M3-2_Assembly.step 9.2MB > 5MB` | The STEP is fine. Hardware will keep producing larger CAD exports. | Default threshold too low; "we shouldn't have hard caps". | **DONE in CADCLAW worktree: bumped default 5MB → 20MB** at `cadharness/rules.py:102` (`PublishAuditModel.blob_size_warn_bytes: int = 20 * 1024 * 1024`). Already configurable per-project via `publish_audit.blob_size_warn_bytes` (set to `0` to disable). |
| `publish.committed blog/**` (4 files) | Author's mistake in the test cadclaw.yaml — `blog/` is the live GitHub Pages content and should NOT be in `ignore_globs`. | LOW-7 still valid — finding text could be clearer. | **DONE: removed `blog/**` from cadclaw.yaml ignore_globs.** |
| `cad.count_mismatch CAD has 17× cbeam but BOM expects 18 (id=67)` | **Intentional.** BOM description literally says "17 reference pieces plus 1 spare for a total order of 18." Some suppliers only sell in pairs. Author confirmed: 17 in design is correct. | **NEW finding MED-6** — v0.6 has no way to express "design qty + spare qty". Tried 3 workarounds, all failed (rule sets fall back to BOM qty for the CAD check). | **No M3-CRETE change.** Will be resolved by MED-6 in v0.7 (add `expected_design_qty` + `spare_qty` rule fields). Current rule has explanatory comment. |
| BOM UTF-8 mojibake (44 corrupt sequences) | `bom/data.json` had `\xc3\xa2\xe2\x82\xac\xe2\x80\x9d` (40×, em-dash mojibake) and `\xc3\x83\xe2\x80\x94` (4×, multiplication-sign mojibake) — cp1252 round-trips. | INFO-9 — CADCLAW could detect this but doesn't yet. | **DONE: rewrote bytes in place.** All 44 sequences replaced (`—` and `×` now correct UTF-8). 64 parts intact, JSON re-parses, file 212 bytes smaller. Shim regenerated. |
| CAD model missing X-axis NEMA23 (count 6 vs 7) | Known WIP per CLAUDE.md ("X-axis: dual plate sandwich, not yet modeled"). 1× X + 2× Y + 4× Z = 7 motors expected; CAD has 6. | MED-5 (the rule-aggregation issue) overlays this — even after MED-5 fix, the underlying truth (1 motor missing from model) will still fire. Not a CADCLAW bug. | **Deferred — author confirmed "not really important for now".** Tracked as design-WIP, not a CADCLAW or BOM bug. Will resolve naturally when X-carriage modeling lands. |

After these fixes, harness re-run dropped from 6/59/16 → 1/58/10. Remaining 10 failures = 4 MED-2 + 3 MED-5 (motor count, includes the X-axis WIP) + 1 MED-6 (cbeam spare) + 1 MED-4 + 1 MED-3.

---

## How to reproduce this test

```bash
# 1. Install (assumes Python 3.11 on PATH)
python -m venv .cadclaw_venv
.cadclaw_venv\Scripts\python.exe -m pip install -e [local-path-redacted]

# 2. Sanity check
.cadclaw_venv\Scripts\cadclaw.exe doctor

# 3. Scaffold + customize rules (M3-CRETE-tuned cadclaw.yaml at the repo root)
cd [local-path-redacted]
.cadclaw_venv\Scripts\cadclaw.exe harness --rules cadclaw.yaml --report-format md -o report.md
.cadclaw_venv\Scripts\cadclaw.exe bom-audit --rules cadclaw.yaml
.cadclaw_venv\Scripts\cadclaw.exe publish-audit --rules cadclaw.yaml
.cadclaw_venv\Scripts\cadclaw.exe claim-audit --rules cadclaw.yaml
```

Test artifacts left in repo:
- `cadclaw.yaml` — M3-CRETE-tuned rule file
- `bom/data.cadclaw.json` — workaround shim for issue #1
- `report.md` — full harness output

---

## Verified working — keep these as regression tests

| What | How tested | Don't break |
|---|---|---|
| Privacy guard (`ALWAYS_PRIVATE`) | M3-CRETE BOM has populated `vendors`, `sku`, `unit_cost` fields. **Zero findings cited any of those keys.** Serializer is dropping them correctly. | `cadharness/bom_loader.py:32` `ALWAYS_PRIVATE = ("vendors", "sku", "unit_cost", "cost", "price", "supplier")` — must stay enforced through every emit path. |
| `doctor` venv-home probe | Test machine had a leftover venv with `pyvenv.cfg` pointing at a deleted Python (`[home-path-redacted] from another machine). Doctor ran on the fresh venv I built and correctly resolved `home = [home-path-redacted] | The probe needs to keep working when `home` exists; needs an explicit *failing* test where `pyvenv.cfg.home` points at a missing path → fail with the path printed. |
| `init_rules.py` — honest about uncertainty | Wrote 0 confident matches, 11 commented-out unknowns from a 64-part BOM. Right default. | Don't lower the confidence threshold to make demos look better — the commented-out output forced me to actually look at the bbox signatures. |
| MCP server starts and registers 17 tools | `doctor` reports `MCP server responds; 17 tools registered.` | Add stdio-subprocess test (doctor's "not checked" list mentions this gap). |

---

## Issues — prioritized

### 🔴 HIGH-1 — BOM loader rejects `{parts: [...]}` (release blocker for any non-fixture project)

**Symptom:** First harness run failed with:
```
cadharness.bom_loader.BomLoadError: BOM JSON must be a list or {items: [...]}, got dict
```

**Root cause:** [`cadharness/bom_loader.py:50-57`](cadharness/bom_loader.py#L50-L57) only accepts top-level list or `{items: [...]}`.

**Why this matters:** `parts` is the more domain-natural key for hardware BOMs and is what M3-CRETE uses (alongside `version`, `generated`, `source`, `notes`). I had to write a `parts→items` shim to continue testing. Any new user with a `parts:` BOM hits this immediately.

**Proposed fix (pick one):**
1. Also accept `data["parts"]` as a synonym for `data["items"]`.
2. Detect the first list-valued key (sketch: `next((v for v in data.values() if isinstance(v, list)), None)`) — risky if BOMs ever have multiple lists.
3. Add a `--bom-list-key parts` CLI override + corresponding `bom_audit.list_key:` rule-file field.

I'd vote (1) + add a deprecation note that says "for new BOMs, prefer `items`" — minimum disruption, supports both conventions.

**Test fixtures to add:**
- `tests/fixtures/m3_crete/bom_real_parts_key.json` — copy of M3-CRETE bom/data.json shape
- `tests/test_bom_loader.py::test_accepts_parts_key`
- `tests/test_bom_loader.py::test_rejects_unknown_top_level_keys` (regression — make sure (2) doesn't make us promiscuous)

---

### 🟠 MED-2 — `forbidden_terms` substring match catches negations and educational mentions

**Symptom:** 4 false-positive `bom.forbidden_term_present` failures on M3-CRETE BOM:

| BOM id | Forbidden term | Actual description text |
|---|---|---|
| 5 | "primary stiffness" | *"These are alignment aids, **not the primary stiffness** or centering method."* |
| 15 | "10mm" | *"Uses 6mm GT2 because the X belt must fit inside the gantry slot; **do not substitute the 10mm belt** used on Y/Z here."* |
| 20 | "6mm" | *"Belt-driven Z — same GT2 10mm belt as Y-axis; X-axis remains 6mm to fit the gantry slot."* (cross-reference is intentional) |
| 24 | "purchased" | *"**No purchased** Z motor brackets in the current reference design."* |

**Root cause:** Dumb substring matching. The descriptions explicitly *warn against* the forbidden thing — that's the whole point of saying it. A match-anywhere rule treats negation and assertion as equivalent.

**Why this matters:** The user has two bad options today: (a) delete the warning and lose useful build-doc content, or (b) accept permanent failures from the gate. Either way the gate stops being trustworthy and gets ignored.

**Proposed fix (graduated):**
1. **Cheap win:** before flagging, look back ~30 chars for negation tokens (`not`, `no`, `never`, `do not`, `don't`, `replaces`, `instead of`, `rather than`). If found, skip.
2. **Better:** support regex per term, e.g.
   ```yaml
   forbidden_terms:
     - "primary stiffness"          # exact substring (current behavior)
     - regex: "(?<!not )(primary|max) stiffness"  # negation-aware
   ```
3. **Best:** split into `forbidden_substring` (current dumb behavior, for stale-tag scenarios) and `forbidden_assertion` (negation-aware, for claim scenarios).

I'd start with (1) — it's a 5-line change and fixes 3 of the 4 cases above. Add a yaml escape hatch (`forbidden_terms_strict: ["primary stiffness"]` or similar) for the rare case where you want dumb substring even with negation.

**Test fixtures to add:** extend `tests/fixtures/m3_crete/bom_*.json` with:
- `bom_negation_in_description.json` — id 5 with the real M3-CRETE phrasing → should PASS once fix lands.
- `bom_anti_substitution.json` — id 15 / id 20 cross-references → should PASS.

---

### 🟠 MED-3 — `claim_audit.stale_terms` doesn't distinguish required attribution / negated mentions / code comments

**Symptom:** 3 false-positive `claim.stale_term` failures on M3-CRETE README + BOM viewer:

| File:line | Term | Actual context |
|---|---|---|
| `README.md:140` | "OpenBuilds" | **CC BY-SA 4.0 license attribution block.** *"V-Slot component CAD models in `CAD/Components/` are based on [OpenBuilds](https://openbuilds.com) designs and are licensed under CC BY-SA 4.0."* — license compliance literally requires this. |
| `bom/index.html:1188` | "Supabase" | JS section comment: `// Initialization (Static JSON — no Supabase)` — i.e. "we removed Supabase." |
| `bom/index.html:1201` | "Supabase" | Same pattern: `// Auth (GitHub link only — no Supabase)` |

**Root cause:** Same as MED-2 — substring scan with no awareness of context (negation, comment markers, license blocks).

**Why this matters:** The OpenBuilds case is especially bad — telling the user to delete a CC BY-SA attribution would be a **license violation**.

**Proposed fix:**
1. Skip lines starting with comment markers by default (`#`, `//`, `<!--`, `--`, `;`) for code/HTML files. They're rarely editorial claims.
2. Add `claim_audit.attribution_files: [LICENSE, NOTICE, COPYING, AUTHORS, ATTRIBUTION]` — files always exempt from stale_terms.
3. Add per-term `allow_in_sections:` regex pattern, e.g. allow "OpenBuilds" inside lines matching `(?i)license|attribution|based on|derived from`.
4. Same negation-aware logic as MED-2 (the "no Supabase" case).

Stack-rank: (1) + (2) covers ~80% of these cases with minimal config burden. (3) is the escape hatch.

**Test fixtures to add:**
- `tests/fixtures/claim_audit/license_attribution.md` — license block mentioning forbidden term → should PASS.
- `tests/fixtures/claim_audit/no_supabase_comment.html` — `<!-- no Supabase -->` and `// no Supabase` → should PASS.

---

### 🟠 MED-4 — `claim.forbidden_absolute "validated"` is too aggressive for default rule

**Symptom:** `README.md:109` flagged for *"...machine learning formulation engine trained on **validated** 3D-printed cementitious specimen data..."*. The sentence describes a **third-party service's** (CEMFORGE) training data, not a claim about M3-CRETE.

**Root cause:** "validated" is a normal English word with many uses outside marketing. The default rule fires on it independent of subject.

**Proposed fix:**
1. Make `forbidden_absolutes` configurable per-project (move out of defaults), since "validated" is heavy-handed for a default.
2. Optional: detect sentence subject (first noun phrase) and only fire when subject is a configured "self_aliases" list (`M3-CRETE`, `this printer`, `our system`, `we`, etc.). This is a bigger change but it's the right shape long-term.

I'd start with (1). The current default flags far too much.

**Test fixture:** `tests/fixtures/claim_audit/third_party_claim.md` — sentence whose subject is a different product.

---

### 🟠 MED-5 — `cad.count_mismatch` reports per-rule against same label, producing redundant findings

**Symptom:** M3-CRETE has 3 BOM rules expecting label `motor_nema23`:
- id 9 (X-axis NEMA23) qty=1
- id 14 (Y-axis NEMA23) qty=2
- id 19 (Z-axis NEMA23) qty=4

CAD has 6 motors. Harness emits **3 separate failures**:
```
CAD has 6× motor_nema23 but BOM/rule expects 1 (id=9).
CAD has 6× motor_nema23 but BOM/rule expects 2 (id=14).
CAD has 6× motor_nema23 but BOM/rule expects 4 (id=19).
```

**Root cause:** The check is rule-by-rule. The user has to mentally sum (1+2+4=7) to see the real story: CAD model is missing 1 motor.

**Proposed fix:** aggregate rules by `expected_label` first. Emit one finding:
```
CAD has 6× motor_nema23, rules sum to 7 (ids 9+14+19 expect 1+2+4). Δ=-1.
```

**Test fixture:** `tests/fixtures/m3_crete/multi_rule_same_label.yaml` — 3 rules → 1 expected finding, not 3.

---

### 🟠 MED-6 — `expected_qty` conflates design count with order count (no way to express spares)

**Symptom:** M3-CRETE BOM id=67 (`C-beam 40×80 × 1000 mm — Frame Member`) has `qty: 18` because the order intentionally includes 1 spare ("17 reference pieces plus 1 spare for a total order of 18" — straight from the BOM description). CAD model has 17 instances (the design uses 17). The harness emits `cad.count_mismatch: CAD has 17× cbeam but BOM/rule expects 18`.

Tried v0.6 workarounds, all failed:
1. **Set `expected_qty: 17` in rule** → `bom.qty_mismatch: BOM id=67 qty=18, expected 17.` — CAD passes but BOM fails.
2. **Set `expected_qty: 18` in rule** → CAD fails (17 vs 18). Original problem.
3. **Omit `expected_qty` from rule** → `cad.count_mismatch` STILL fires because the harness falls back to BOM `qty` when the rule doesn't specify. There's no v0.6 way to disable the count check on a per-rule basis short of moving the label to `ignore_labels` (which kills all validation for that label).

**Root cause:** The semantic model conflates "how many should be in the design" (CAD) with "how many should be ordered" (BOM). Real-world procurement always orders more than designed — for breakage, packaging multiples (some sources only sell pairs), prototype iteration, kit-completeness margin.

**Proposed fix:**
1. Add `expected_design_qty` (validated against CAD) and `expected_order_qty` (validated against BOM `qty`) as separate rule fields. Either or both can be specified.
2. Add `spare_qty: 1` as syntactic sugar — derives `expected_order_qty = expected_design_qty + spare_qty`.
3. Add `skip_qty_check: true` as an escape hatch when the design has structural qty variation (e.g. user-configurable variants).

I'd ship (1) + (2) together. (2) is what most BOMs need.

```yaml
# Proposed v0.7 syntax
- id: 67
  expected_design_qty: 17
  spare_qty: 1
  expected_mfg_type: buy
  expected_label: cbeam
```

**Test fixture:** `tests/fixtures/m3_crete/bom_with_spares.json` — id with `qty: 18`, rule with `expected_design_qty: 17, spare_qty: 1`, CAD with 17 instances → should PASS.

---

### 🟡 LOW-6 — `bom.unmapped_item` is too noisy at warn-level (51/64 items warned on real project)

**Symptom:** M3-CRETE harness produced 51 `bom.unmapped_item` warnings for items the user reasonably hasn't written CAD-mapping rules for: electronics (BTT Kraken, Pi 5, touchscreen, PSU), fasteners (M5 cap screws, washers, heat-set inserts), wire/cable (silicone power wire, drag chain cable), consumables (ferrules, sleeving, labels).

**Root cause:** Default `EXEMPT_MFG_TYPES = ("consumable", "electronic", "fastener")` from [`bom_loader.py:33`](cadharness/bom_loader.py#L33) doesn't help because M3-CRETE uses `mfg_type: "buy"` for everything purchasable — including electronics — which is semantically reasonable from a procurement perspective. Forcing users to re-categorize all electronics as `mfg_type: "electronic"` is intrusive.

**Why this matters:** signal-to-noise. A 51-warn flood drowns the 4 real failures.

**Proposed fix (pick one or stack):**
1. Demote `bom.unmapped_item` from `warn` to `info` severity by default (most useful).
2. Add keyword-based auto-exempt: regex match item names against `(?i)screw|nut|washer|wire|cable|ferrule|kit|terminal|connector|stripper|crimp|sleev|label|tie|gland|enclos|panel|filter|lighting|camera|hopper|tubing|fitting`. Highly heuristic but catches 80% of the noise.
3. Add `bom_audit.exempt_ids: [25, 26, 27, ...]` for one-line bulk-exempt. Tedious but explicit.
4. Add `bom_audit.exempt_categories: [electronics, hardware, fasteners, ...]` matching the user's existing BOM `category` field if present. (M3-CRETE has `category` per item; CADCLAW could read it.)

Stack-rank: (1) is the most painless win. (4) is the cleanest because it leverages existing BOM structure.

**Test fixture:** rerun M3-CRETE harness → expect bom.unmapped_item count to drop ≥80%.

---
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

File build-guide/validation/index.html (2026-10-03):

M3-CRETE by Sunnyday Technologies

# M3-CRETE Preliminary Motion Checkout

These development notes cover limited current, direction, sensorless-homing, and Z-alignment observations for qualified technical teams. They are not the last step before printing and do not replace a risk assessment, engineered controls, guarding, professional electrical review, commissioning plan, or material-process validation.

Part

4 of 4

Time

Defined by test plan

Audience

Qualified team

Needs

Approved risk controls

Safety first

Software-controlled axes can move unexpectedly. Do not energize or test motion from this page alone. A qualified team must first define exclusion zones, energy isolation, guarding, stop/reset behavior, supervision, and an approved test plan. Keep all material-delivery equipment isolated during preliminary motion work.

## What you need

- A fully assembled frame (Part 1), wired (Part 2), with software installed and showing Klipper: Ready (Part 3).
- A tape measure or calipers to check the corners are level.
- A browser open to Mainsail (the printer's dashboard).
- Notes from Part 3 on any motor that jogged the wrong direction.

## Words to know

Run current

How much electrical current each motor gets. More current = more force, but more heat.

StallGuard

A feature inside the motor driver that senses when a motor pushes against a hard stop ("stalls"). We use it instead of limit switches.

Sensorless homing

Finding the "zero" position by driving an axis until it gently stalls against the frame, using StallGuard.

SGT

The StallGuard sensitivity setting. Higher = less sensitive; lower = more sensitive.

Coplanar / level

All four corners of the gantry sitting at the same height.

Dry run

Moving the printer through its motions with no concrete, to check everything works.

## Validate the Z axis

1

### Set the motor current

In Mainsail, open printer.cfg. For each Z driver section ([tmc5160 stepper_z], stepper_z1, z2, z3), find run_current. Start at 1.2 to confirm nothing is wrong, then raise toward 1.5–1.8 so the motors can lift the gantry. Never go above about 2.0 for these 2.8 A motors. Click Save & Restart after changes.

Watch the heat

After a few minutes of holding, a motor should be warm, not too hot to touch. If it is too hot, lower run_current.

2

### Fix any wrong directions

Using your notes from Part 3: if a corner went down when you sent it up, that motor's direction is reversed. In printer.cfg, find that motor's dir_pin and add or remove a ! in front of the pin name. Save & Restart, then re-test with ZJOG MOTOR=n DIST=5 VEL=3. All four should now raise their corner with a positive number.

3

### Tune the stall sensing (this is the careful part)

Each Z motor must reliably feel when it reaches the top of the frame. Tune one driver at a time. First make sure run_current is already at your final value (the sensing changes if you change current later). Then adjust driver_SGT in that driver's section:

- If a motor stops too early (before reaching the top): raise driver_SGT by 1 (less sensitive).
- If a motor crashes into the top without stopping: lower driver_SGT by 1 (more sensitive).

Change one number, run FIRMWARE_RESTART, and test again. The command ZSTATUS shows live load numbers to help. Repeat until each corner stops cleanly and repeatably at the top.

4

### Home all four corners

In the console, type:

HOME_Z

All four corners drive up. You should see (and hear) four separate gentle stops as each corner meets the top, then a small back-off. Each corner sets its own zero at the point it stalled. This is how the printer levels itself without any probe.

5

### Check the gantry is level

After homing, measure the height of the gantry at each of the four corners (from the build surface, or from the base). They should all match within a couple of millimeters. If one corner is off, re-check that corner's belt tension and re-run the stall tuning for it, then HOME_Z again.

6

### Dry-run the Z motion

Jog the gantry up and down through its travel a few times (small moves first, then larger). Watch and listen for: smooth motion, no grinding, no slipping belts, and no corner lagging behind. The four corners should stay level as they move.

## Professional safety-function verification (outside this guide)

7

### Record qualified stop-function verification

Do not design or test an emergency-stop function from this public guide. A qualified controls/electrical professional must define the required stop behavior, energy removal, reset/restart controls, fault response, test method, and acceptance evidence for the actual machine and jurisdiction.

8

### Route the system to a formal readiness review

The observations below can support a review, but they are not a readiness gate. Printing remains blocked until responsible qualified owners approve the complete mechanical, electrical, controls, guarding, pump/pressure, material, facility, operating, and emergency-response scope.

## Preliminary motion-check evidence

Record these observations only within an approved test plan. Completion does not authorize material printing.

- Motor current set to working value and motors stay only warm, not hot.
- All four Z corners jog the correct direction.
- Stall sensing tuned — each corner stops cleanly and repeatably at the top.
- HOME_Z gives four clean stops and a back-off, every time.
- Gantry measures level at all four corners after homing.
- Z dry-run is smooth, no slipping or lagging.
- Qualified professional's separate stop-function verification record is identified.
- Equivalent axis-specific checks are defined for X, Y, and any extruder drive; no axis is inferred from Z results.

## If you get stuck

- See the per-stage commissioning notes in the firmware repo: M3-CRETE-FIRMWARE (https://github.com/sunnyday-technologies/M3-CRETE-FIRMWARE).
- Ask on M3-CRETE Discussions (https://github.com/sunnyday-technologies/M3-CRETE/discussions).
- Klipper sensorless-homing reference: klipper3d.org (https://www.klipper3d.org/Sensorless_Homing.html).

Next

Completing these limited observations does not mechanically or electrically validate the machine and does not make it ready to print. Qualified engineering, electrical, controls, guarding, pump/pressure, material, facility, and commissioning reviews remain separate requirements.

M3-CRETE is an experimental open-hardware reference, not a finished certified appliance or construction machine. It is intended for qualified technical users, R&D labs, supervised institutional programs, and experienced builders. Any AC mains wiring, control-box integration, grounding, disconnects, or emergency-stop power work must be done by qualified personnel or a licensed electrician where required. Hardware is published under CERN-OHL-W-2.0; this guide is CC BY 4.0.

© 2026 Sunnyday Technologies LLC · sunn3d.com · m3-crete.com · Build Guide

Part 4 of 4 · Validation

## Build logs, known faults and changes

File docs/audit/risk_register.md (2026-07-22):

# M3-CRETE Public-Scope Risk Register

Opened: 2026-07-03 · Last updated: 2026-07-21

This register tracks public-scope cleanup risks. It is a working remediation
record, not a legal conclusion.

| ID | Severity | Risk | Affected paths | Mitigation | Status |
| --- | --- | --- | --- | --- | --- |
| R-001 | P0 | Public control-panel planner could be interpreted as control-panel build guidance despite disclaimers. | `control-panel/index.html`, `control-panel/tool.html`, `blog/control-panel-layout-tool/index.html`, `images/control-panel-tool.png` | Planner removed; announcement post replaced with a supersession notice; nav links and blog card removed; screenshot deleted. | **Closed 2026-07-21** — live-verified |
| R-002 | P0 | Homepage/README/build guide imply broad replication by anyone, jobsite/field use, or school/student use. | `index.html`, `README.md`, `build-guide/**` | Reframe as experimental reference for qualified teams in controlled R&D, lab, or supervised institutional settings. | **OPEN** — rewrite drafted, not landed. Owner review required |
| R-003 | P0 | Public BOM can look like a shopping list for high-current or professional electrical scope. | `bom/data.json`, `bom/index.html`, `config.js` | Power/safety items replaced with professional/private scope placeholders; conductor sizing removed; static table and variant config synced. | **Closed 2026-07-21** — live-verified |
| R-004 | P1 | SEO/social/press/blog metadata promotes control-panel planner or DIY framing. | `blog/**`, `press/**`, `sitemap.xml`, `.zenodo.json`, `llms.txt` | Planner navigation and promotion removed. Sitemap never listed the planner route. | **Closed 2026-07-21** for planner promotion. DIY-framing metadata rides with R-002 |
| R-005 | P1 | Contributors or agents may reintroduce prohibited claims or power-control guidance. | repo-wide | AGENTS rules, PR/issue templates, CODEOWNERS, review policy, and a warning-only static content guard. | **Closed 2026-07-21** — guard strengthened, see below |
| R-006 | Release blocker | Owner/legal/electrical review cannot be completed by an agent. | release package | Human sign-off. | **Reduced** — electrical arm closed by withdrawal; owner arm open |

## R-005: the original guard did not work

The guard as first written was verified against the pre-remediation tree on
2026-07-21 and reported **"no warnings"** on content that provably contained
`E-stop cuts 24V`, `30A contacts`, and `12AWG handles 25A`. It was a
marketing-claim linter (`UL approved`, `turnkey`, `jobsite ready`), not an
electrical-content check, and it would have given false assurance.

Three defects were fixed:

1. `.js` was not in the scanned suffixes, so `config.js` — which carries a copy
   of every BOM item name — was invisible to it.
2. `control-panel/**` and `blog/control-panel-layout-tool/**` were on the
   allow-list, exempting exactly the paths under remediation.
3. No term matched circuit-design or conductor-sizing phrasing.

The guard now also decodes `\uXXXX` escapes before scanning, because escaped
non-ASCII (an em dash in an item name) hid text from the plain scan. Re-run
against the pre-remediation tree it produces **15 warnings** across
`bom/data.json`, `bom/index.html`, and the planner post. It is still
warning-only and still not a substitute for reading the diff.

## R-006: scope after 2026-07-21

R-006 has three arms. One is closed, one is open, one is conditional.

**Electrical review — CLOSED, not applicable.** The drafts that required a
qualified electrical/control-panel reviewer were **withdrawn rather than
reviewed** (see below). No public M3-CRETE content now defines low-voltage
connector values, current limits, fuse behaviour, or professional power/control
scope, so there is nothing for an electrical reviewer to sign off. Re-opens
automatically if any such content is proposed again.

**Owner review — OPEN.** R-002 is the remaining public-scope risk. The rewrite
of `index.html`, `build-guide/**`, `press/**`, and `blog/index.html` is drafted
but not landed, and is a positioning decision, not a safety fix.

**Counsel review — CONDITIONAL.** Required only if the professional-user
acknowledgement, revised terms, or new disclaimer language ships. The
disclaimer and boundary text currently on `main`
(`DISCLAIMER.md`, `SAFETY_NOTICE.md`, `ELECTRICAL_SCOPE_BOUNDARY.md`) is
unchanged from before this remediation and is not gated by R-006.

## Withdrawn 2026-07-21 — electrical drafts

The following were drafted during the 2026-07-03 pass and are **withdrawn, not
published**:

- `docs/electrical/24v_low_voltage_interface.md`
- `docs/electrical/controller_enclosure_outline.md`
- `docs/electrical/professional_power_control_scope.md`
- `docs/electrical/electrical_scope_boundary.md`
- `docs/commercial/professional_user_acknowledgement_draft.md`

Rationale: every rating in the 24 V interface draft was `TBD by electrical
reviewer` — voltage range, maximum current, connector family, pinout, branch
fuse, reverse-polarity protection. Publishing an interface specification whose
values are all unresolved implies an interface is defined when it is not, which
is worse than publishing nothing. `ELECTRICAL_SCOPE_BOUNDARY.md` is already
public on `main` and already states what is and is not provided, which is the
job these drafts were written to do.

Withdrawing them removes the only content that required a licensed reviewer.

The drafts are preserved in the retired `safety/public-scope-freeze` bundle and
can be revived, but must not be published without qualified electrical review
and owner sign-off. The branch was never pushed to origin, so the bundle is the
only copy:

```
_cleanup-quarantine\m3-crete-public-scope-freeze-20260721.bundle   (25 MB, commit c04fe6e)
git init restore && cd restore && git fetch <bundle> "refs/heads/*:refs/heads/*"
```

Restore was tested on 2026-07-21 before the local branch was deleted: 262 files,
complete history, all five withdrawn documents recoverable.

## Release blockers

- Owner review required for all public-scope changes (R-002 outstanding).
- Counsel review required for disclaimer, terms, commercial, acknowledgement,
  and supersession language **if any of it changes**.
- Qualified electrical/control-panel review required for any future public text
  defining low-voltage connector values, current limits, fuse or
  current-limiting behaviour, operator interface boundaries, motor-driver
  enclosure constraints, or professional power/control scope.

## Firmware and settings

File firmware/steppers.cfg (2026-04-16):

# ============================================================================
# Stepper Motors — Motion + Extruder
# ============================================================================
# Driver allocation on BTT Kraken (8 onboard TMC5160):
#   DRIVER0 -> stepper_x       (single X motor)
#   DRIVER1 -> stepper_y       (Y-left, primary)
#   DRIVER2 -> stepper_y1      (Y-right, secondary — dual drive, anti-racking)
#   DRIVER3 -> stepper_z       (Z front-left)
#   DRIVER4 -> stepper_z1      (Z front-right)
#   DRIVER5 -> stepper_z2      (Z rear-left)
#   DRIVER6 -> stepper_z3      (Z rear-right)
#   DRIVER7 -> extruder        (nozzle VALVE — small motor, ≤3A)
#
# The feed PUMP (NEMA34) runs on an EXTERNAL driver via Kraken's MOTOR7 header
# because NEMA34 needs 5–7A and TMC5160 tops out at ~3A RMS. See the extruder
# architecture notes further down.
#
# Belt / pulley math (same on every motion axis):
#   GT2 belt pitch:     2 mm
#   Pulley:             20 tooth
#   rotation_distance:  2 * 20 = 40 mm/rev
#   Full step:          200 steps/rev (1.8° motors)
#   Microsteps:         16 (with interpolation, see tmc.cfg)
#   Resolution:         40 / (200 * 16) = 0.0125 mm/microstep
#
# IMPORTANT — pin names below match BTT's official Kraken Klipper example config
# (example-kraken.cfg upstream). Verify against your board revision on first boot.
# ============================================================================

# ----------------------------------------------------------------------------
# X AXIS — belt-pinion drive (motor travels WITH the printhead)
# ----------------------------------------------------------------------------
# Architecture: the X motor is mounted on the X-carriage and its pulley
# rolls along a single fixed strand of 6mm GT2 belt that's anchored at
# both ends of the gantry beam. Rotating the pinion drives the carriage
# along the belt like a rack-and-pinion — there's no belt loop.
#
# Why belt-pinion on X:
#   - No 4m+ belt loop to stretch and resonate
#   - Simpler tensioning (two fixed anchors, no idler pulleys)
#   - Scales cleanly to longer X spans (M3-4 variant etc.)
#
# Consequences for this config:
#   - rotation_distance is UNCHANGED (40 = 20T * 2mm pitch, same math)
#   - Motor wires travel in the X drag chain alongside the printhead
#   - Direction polarity is often inverted from a loop-drive cartesian —
#     if X+ jogs the wrong way on first-motion test, toggle the '!' on
#     dir_pin below
#   - Moving mass includes the motor itself — keep accel conservative
#     until input shaping is tuned
# ----------------------------------------------------------------------------
[stepper_x]
step_pin: PE2
dir_pin: PE1                 # toggle '!' prefix if first-motion test moves wrong way
enable_pin: !PE4
rotation_distance: 40
microsteps: 16
full_steps_per_rotation: 200
endstop_pin: tmc5160_stepper_x:virtual_endstop
position_endstop: 0
position_min: 0
position_max: 2000
homing_speed: 25             # sensorless — start conservative
homing_retract_dist: 0       # sensorless: MUST be 0 (no retract on stall)

# ----------------------------------------------------------------------------
# Y AXIS — dual motors at the REAR (anti-racking, loop-driven)
# ----------------------------------------------------------------------------
# Both Y motors are mounted at the REAR of the machine. The belts run from
# rear pulleys forward to idlers at the front and back. Home position (Y=0)
# is at the FRONT of the machine, so Y+ moves the gantry AWAY from home
# (toward the rear motors). If this is reversed on first-motion test,
# toggle the '!' on dir_pin below — BOTH Y motors must flip together.
# ----------------------------------------------------------------------------
[stepper_y]
step_pin: PF12
dir_pin: PF11
enable_pin: !PB7
rotation_distance: 40
microsteps: 16
full_steps_per_rotation: 200
endstop_pin: tmc5160_stepper_y:virtual_endstop
position_endstop: 0
position_min: 0
position_max: 1000
homing_speed: 25
homing_retract_dist: 0

[stepper_y1]
step_pin: PD7
dir_pin: PD6
enable_pin: !PF10
rotation_distance: 40
microsteps: 16
full_steps_per_rotation: 200
# y1 follows y — no endstop, homes together with the primary

# ----------------------------------------------------------------------------
# Z AXIS — four independent motors, belt-driven, sensorless homing to top
# ----------------------------------------------------------------------------
# Homing strategy: drive all 4 Z up until each stalls independently against
# the top brace. Each corner reaches mechanical stop at its true Z_max,
# giving 4-corner coplanarity without a physical probe. Z_TILT_ADJUST is
# still available as a recalibration tool — see z_tilt.cfg.
#
# Position values: Z=0 is the build surface, Z=1000 is the top brace.
# position_endstop = position_max because we home UP.
# ----------------------------------------------------------------------------

[stepper_z]
step_pin: PD3
dir_pin: PD2
enable_pin: !PD5
rotation_distance: 40
microsteps: 16
full_steps_per_rotation: 200
endstop_pin: tmc5160_stepper_z:virtual_endstop
position_endstop: 1000
position_min: -2             # small negative allowance for Z offset calibration
position_max: 1000
homing_speed: 10             # slow — belts under mass
homing_retract_dist: 0

[stepper_z1]
step_pin: PC9
dir_pin: PC8
enable_pin: !PD4
rotation_distance: 40
microsteps: 16
full_steps_per_rotation: 200

[stepper_z2]
step_pin: PF9
dir_pin: PF8
enable_pin: !PF7
rotation_distance: 40
microsteps: 16
full_steps_per_rotation: 200

[stepper_z3]
step_pin: PE6
dir_pin: PA14
enable_pin: !PE5
rotation_distance: 40
microsteps: 16
full_steps_per_rotation: 200

# ============================================================================
# EXTRUDER SYSTEM — Two-stage fluid handling
# ============================================================================
# M3-CRETE does NOT use a single pushing pump like an FDM extruder. Instead,
# it uses TWO coordinated steppers in series:
#
#     G1 E... moves from the slicer
#                |
#                v
#     +------------------+       every E move drives both steppers in sync
#     |                  |
#     |   [extruder]     |  <-- NOZZLE VALVE
#     |   "valve"        |      - small motor (or servo), ≤3A
#     |                  |      - 1% retraction capability for clean stops
#     |                  |      - pressure_advance = 0 (valve is local, fast)
#     |                  |      - lives at the printhead
#     |                  |
#     +---------^--------+
#               |  sync
#               |
#     +---------v------------+
#     |                      |
#     |  [extruder_stepper   |  <-- FEED PUMP (the heavy NEMA34)
#     |   pump_feed]         |      - lives UPSTREAM of the hose
#     |                      |      - pressure_advance ~= 0.8 (tune)
#     |                      |        to pre-pressurize hose before
#     |                      |        valve commanded moves
#     |                      |      - rotation_distance can differ from
#     +----------------------+        the valve (different mech ratios OK)
#
# KEY INSIGHT: the valve is registered as [extruder] because the slicer
# thinks of E moves as nozzle output. The feed pump is an [extruder_stepper]
# synced to the valve. Per-stepper pressure_advance lets us have PA=0 on
# the valve AND PA~=0.8 on the feed pump simultaneously — the feed pump's
# PA offset runs its motion ahead in time so material is already arriving
# at the valve when the valve opens.
#
# Set PA at runtime via:
#   SET_PRESSURE_ADVANCE EXTRUDER=extruder   ADVANCE=0.0   # valve
#   SET_PRESSURE_ADVANCE EXTRUDER=pump_feed  ADVANCE=0.8   # feed pump
# Or use the SET_PUMP_PA macro in macros.cfg.
# ============================================================================
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

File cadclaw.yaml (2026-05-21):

schema_version: "0.7"

meta:
  project: m3-crete
  description: "M3-CRETE — real rule file for CAD/M3-2_Assembly.step + bom/data.json (v0.7, 2026-04-26)"
  step: CAD/M3-2_Assembly.step
  bom: bom/data.json

labels:
  vwheel:           [10.2, 23.9, 23.9]
  cbeam:            [40.0, 80.0, 1000.0]
  motor_nema23:     [56.4, 56.4, 76.6]
  plate:            [3.0, 88.0, 127.0]
  pulley:           [14.0, 15.0, 15.0]
  smooth_idler:     [12.7, 22.0, 22.0]
  z_motor_mount:    [4.0, 80.0, 97.0]   # corrected — was 107; user-authored sig is 97 (cloned to all 4 Z + 2 Y in assembly)
  bot_spacer_idler: [4.0, 80.0, 100.0]
  t_gusset:         [4.0, 160.0, 280.0]
  idler_bracket:    [5.0, 30.0, 30.0]
  # 2026-04-29 additions (promoted from CAD/self_check.py LABELS)
  shim:             [4.0, 40.0, 80.0]
  xcarr_bolt:       [5.0, 16.0, 16.0]   # M5 SHCS heads on X-carriage
  xcarr_axle:       [9.0, 9.0, 31.5]    # V-wheel axles
  xcarr_washer:     [1.0, 10.0, 10.0]
  xcarr_spacer:     [3.2, 10.0, 10.0]
  2040_insert:      [20.0, 40.0, 1000.0]   # internal X-direction 4080 reinforcement (B+b)

belt_heuristic: true

expected_inventory: {}

bom_audit:
  bom_path: bom/data.json
  # AGENTS.md: fastener accounting is text-based (BOM line items), not bbox-based.
  # The xcarr_* + shim labels are placement/inventory tracking only — no BOM rule needed.
  ignore_labels: [other, belt, shim, xcarr_bolt, xcarr_axle, xcarr_washer, xcarr_spacer]
  # v0.7 / LOW-6: drop noise from items that aren't expected to have CAD
  # geometry (electronics, fasteners, consumables, optional upgrades).
  # Case-insensitive substring match against each item's `category` field.
  exempt_categories:
    - "Electronics"
    - "Fasteners"
    - "Optional"
    - "Concrete Extrusion"
  rules:
    - id: 5
      expected_qty: 12
      expected_mfg_type: buy
      forbidden_terms:
        - "maximum rigidity"
        - "primary stiffness"
    - id: 9
      expected_qty: 1
      expected_mfg_type: buy
      expected_label: motor_nema23
    - id: 10
      expected_qty: 2
      expected_mfg_type: buy
      required_terms: ["10mm"]
      forbidden_terms: ["6mm"]
    - id: 14
      expected_qty: 2
      expected_mfg_type: buy
      expected_label: motor_nema23
    - id: 15
      expected_qty: 1
      expected_mfg_type: buy
      required_terms: ["6mm"]
      forbidden_terms: ["10mm"]
    - id: 17
      expected_qty: 32
      expected_mfg_type: buy
      expected_label: vwheel
    - id: 19
      expected_qty: 4
      expected_mfg_type: buy
      expected_label: motor_nema23
    - id: 20
      expected_qty: 4
      expected_mfg_type: buy
      required_terms: ["10mm"]
      # "6mm" intentionally not forbidden: BOM description for the Z-axis
      # belt cross-references the X-axis 6mm belt for context. v0.7 / MED-2
      # negation lookback doesn't help since the cross-reference isn't
      # negated. Either edit description, switch to use_regex with a
      # lookbehind, or accept the cross-reference (chosen here).
    - id: 24
      expected_qty: 4
      expected_mfg_type: print
      forbidden_terms:
        - "aluminum"
        - "machined"
        - "purchased"
        - "L-bracket"
        - "steel"
    - id: 65
      expected_qty: 3
      expected_unit: "bars (1.0m each)"
      expected_mfg_type: buy
      expected_label: 2040_insert    # 2026-04-29: linked to placed insert geometry
      forbidden_terms:
        - "JB Weld"
        - "West System"
        - "bonded"
        - "custom 2m cut"
    - id: 67
      # v0.7 / MED-6: design qty (CAD) and order qty (BOM) are now separate.
      # CAD has 17 reference pieces; BOM orders 18 (+1 spare per description).
      expected_design_qty: 17
      spare_qty: 1
      expected_mfg_type: buy
      expected_label: cbeam
    - id: 75
      expected_qty: 2   # 2026-04-29 V1.0: only Y-motors use this plate; Z-motors use bot_spacer_idler
      expected_mfg_type: print
      expected_label: z_motor_mount
    - id: 77
      expected_qty: 2
      expected_mfg_type: print
      expected_label: t_gusset
    - id: 79
      expected_qty: 8   # 2026-04-29 V1.0: 4 corners × top+bottom (top = Z-motor mount)
      expected_mfg_type: print
      expected_label: bot_spacer_idler
    - id: 81
      expected_qty: 0   # 2026-04-29 V1.0: deprecated, role moved to id 75
      expected_mfg_type: print
      expected_label: ymount
    - id: 83
      expected_qty: 32
      expected_mfg_type: buy

claim_audit:
  scan_paths:
    - README.md
    - docs/
    - bom/index.html
  stale_terms:
    - "JB Weld"
    - "West System"
    - "custom 2m cut"
    - "production-ready"
    - "production ready"
    - "OpenBuilds"
    - "Supabase"
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

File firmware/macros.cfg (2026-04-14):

# ============================================================================
# Macros — START_PRINT / END_PRINT / Pump Control
# ============================================================================
# Concrete printing is fundamentally different from FDM in a few ways that
# change how these macros look:
#   - No bed heating, no nozzle heating, no filament retraction
#   - "Purge" means priming the pump line with wet mix
#   - "End" means flushing the line with water before the mix sets
#   - Print failures are VERY expensive (drying concrete in the line)
#   - Two-stage fluid system: feed pump (PA>0) + nozzle valve (PA=0)
# ============================================================================

# ----------------------------------------------------------------------------
# START_PRINT — called at the top of every sliced gcode file
# ----------------------------------------------------------------------------
[gcode_macro START_PRINT]
gcode:
    M117 Homing axes
    G28
    M117 Levelling gantry
    # Z_TILT_ADJUST            ; uncomment once a probe is wired in
    M117 Setting pump pressure advance
    # Valve runs with zero PA — it's a local actuator
    SET_PRESSURE_ADVANCE EXTRUDER=extruder ADVANCE=0.0
    # Feed pump runs ahead of valve to pre-pressurize hose. Tune 0.3 to 1.5.
    SET_PUMP_PA ADVANCE=0.8
    M117 Priming pump
    # PUMP_PRIME               ; uncomment after first pump calibration
    M117 Printing...

# ----------------------------------------------------------------------------
# END_PRINT — called at the end of every sliced gcode file
# ----------------------------------------------------------------------------
[gcode_macro END_PRINT]
gcode:
    M117 Print complete — FLUSH LINE NOW
    G91
    G1 Z50 F600               ; lift Z 50mm
    G90
    G1 X50 Y50 F3000          ; park near origin
    # CRITICAL: the user must flush the pump line with water within 5 min
    # or concrete will cure inside it. PUMP_FLUSH macro below.
    M117 FLUSH LINE WITHIN 5 MIN

# ----------------------------------------------------------------------------
# CANCEL_PRINT — user-invoked panic stop
# ----------------------------------------------------------------------------
[gcode_macro CANCEL_PRINT]
rename_existing: CANCEL_PRINT_BASE
gcode:
    M117 CANCELLED — FLUSH LINE
    CANCEL_PRINT_BASE
    G91
    G1 Z50 F600
    G90
    G1 X50 Y50 F3000

# ----------------------------------------------------------------------------
# PUMP_PRIME — run the pump to fill the line with wet mix
# ----------------------------------------------------------------------------
# Runs both the valve and feed pump together (they're synced) so concrete
# flows through the entire line and out the nozzle.
# ----------------------------------------------------------------------------
[gcode_macro PUMP_PRIME]
gcode:
    {% set PRIME_LENGTH = params.LENGTH|default(100)|float %}
    {% set PRIME_SPEED = params.SPEED|default(10)|float %}
    M117 Priming pump {PRIME_LENGTH}mm at {PRIME_SPEED}mm/s
    G91
    M83                       ; relative extrusion
    G1 E{PRIME_LENGTH} F{PRIME_SPEED * 60}
    G90

# ----------------------------------------------------------------------------
# PUMP_FLUSH — run water through the line after print
# (Assumes you have a manual valve to switch pump intake from mix to water)
# ----------------------------------------------------------------------------
[gcode_macro PUMP_FLUSH]
gcode:
    {% set FLUSH_LENGTH = params.LENGTH|default(500)|float %}
    {% set FLUSH_SPEED = params.SPEED|default(20)|float %}
    M117 Flushing pump — switch intake to WATER
    G4 P5000                  ; 5 second pause for operator to switch valve
    G91
    M83
    G1 E{FLUSH_LENGTH} F{FLUSH_SPEED * 60}
    G90
    M117 Flush complete

# ----------------------------------------------------------------------------
# SET_PUMP_PA — set pressure advance on the feed pump independently
# ----------------------------------------------------------------------------
# The feed pump runs AHEAD of the nozzle valve by this many seconds worth
# of flow so the hose is pre-pressurized when the valve opens. Tune by
# printing a corner-test pattern and checking how much the nozzle output
# lags (needs MORE PA) or bulges (needs LESS PA) after direction changes.
#
# Typical range for concrete hoses:
#   0.3 — short stiff hose, thin mix
#   0.8 — default starting point
#   1.5 — long compliant hose, thick mix
#
# Note: this macro ONLY touches pump_feed, never extruder. The valve stays
# at PA=0 no matter what.
#
# Usage:
#   SET_PUMP_PA ADVANCE=0.8
#   SET_PUMP_PA ADVANCE=0.5 SMOOTH_TIME=0.06
# ----------------------------------------------------------------------------
[gcode_macro SET_PUMP_PA]
gcode:
    {% set ADV = params.ADVANCE|default(0.8)|float %}
    {% set SMOOTH = params.SMOOTH_TIME|default(0.040)|float %}
    SET_PRESSURE_ADVANCE EXTRUDER=pump_feed ADVANCE={ADV} SMOOTH_TIME={SMOOTH}
    M117 Pump PA: {ADV} (smooth {SMOOTH})

# ----------------------------------------------------------------------------
# PUMP_UNSYNC / PUMP_RESYNC — toggle feed pump independence
# ----------------------------------------------------------------------------
# Use PUMP_UNSYNC before manually jogging the pump (e.g. to fill the hopper
# without opening the valve). Use PUMP_RESYNC to return to normal coordinated
# operation.
# ----------------------------------------------------------------------------
[gcode_macro PUMP_UNSYNC]
gcode:
    SYNC_EXTRUDER_MOTION EXTRUDER=pump_feed MOTION_QUEUE=
    M117 Feed pump UNSYNCED — manual control

[gcode_macro PUMP_RESYNC]
gcode:
    SYNC_EXTRUDER_MOTION EXTRUDER=pump_feed MOTION_QUEUE=extruder
    M117 Feed pump RESYNCED to valve

# ----------------------------------------------------------------------------
# SHOW_SG — quick readout of StallGuard values for homing tuning
# ----------------------------------------------------------------------------
[gcode_macro SHOW_SG]
gcode:
    M117 StallGuard values (RESULT lower = closer to stall)
    DUMP_TMC STEPPER=stepper_x
    DUMP_TMC STEPPER=stepper_y
    DUMP_TMC STEPPER=stepper_y1
    DUMP_TMC STEPPER=stepper_z
    DUMP_TMC STEPPER=stepper_z1
    DUMP_TMC STEPPER=stepper_z2
    DUMP_TMC STEPPER=stepper_z3

# ----------------------------------------------------------------------------
# M3-CRETE status LED placeholder (if you add neopixels later)
# ----------------------------------------------------------------------------
# [neopixel status_led]
# pin: PB0                    ; example — pick a free PWM pin
# chain_count: 8
# initial_RED: 0.0
# initial_GREEN: 0.5
# initial_BLUE: 0.0

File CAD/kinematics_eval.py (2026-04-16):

"""
M3-CRETE M3-2 Kinematics & Statics Evaluation
===============================================
Printhead: 3 kg (with hose load)
Frame: 4080 C-beam 1000mm, 2080 gantry beam 2000mm (spliced)
Motors: 7x NEMA23 (1X + 2Y + 4Z), GT2 10mm belt, 20T pulleys

Evaluates:
  1. Gantry beam deflection (worst-case center load)
  2. Motor torque budgets per axis
  3. Maximum acceleration & speed per axis
  4. Belt tension analysis & safety margins
  5. Dual-Y racking analysis
  6. Z-axis lift capacity
  7. NEMA17 vs NEMA23 feasibility (geared & direct)

All calculations use conservative (worst-case) assumptions.
"""
import math

print("=" * 70)
print("M3-CRETE M3-2 KINEMATICS & STATICS EVALUATION")
print("=" * 70)

# ============================================================
# PHYSICAL CONSTANTS & MATERIAL PROPERTIES
# ============================================================
g = 9.81  # m/s^2

# Aluminum 6063-T5 (typical V-slot extrusion alloy)
E_al = 69e9       # Pa (Young's modulus)
rho_al = 2700     # kg/m^3
sigma_yield = 145e6  # Pa (yield strength)

# GT2 10mm belt
BELT_WIDTH = 10     # mm
BELT_PITCH = 2      # mm
# Steel-core GT2 10mm: ~900N breaking strength, ~450N recommended max working
BELT_BREAK_N = 900
BELT_WORK_N = 450
# Tooth shear: ~30N per tooth engagement (conservative)
TOOTH_SHEAR_N = 30

# GT2 20-Tooth pulley
PULLEY_TEETH = 20
PULLEY_PITCH_DIA = PULLEY_TEETH * BELT_PITCH / math.pi  # mm
PULLEY_PITCH_R = PULLEY_PITCH_DIA / 2.0 / 1000.0  # m

# ============================================================
# MOTOR SPECS
# ============================================================
# NEMA23 — typical 2.8A bipolar, 8mm shaft
NEMA23_HOLDING_TORQUE = 1.89    # Nm (typical 57x56mm, 2.8A)
NEMA23_DETENT_TORQUE = 0.05     # Nm
NEMA23_ROTOR_INERTIA = 480e-7   # kg*m^2 (480 g*cm^2)
NEMA23_WEIGHT = 1.05            # kg
NEMA23_MAX_RPM = 1200           # practical limit with TMC5160 at 24V
NEMA23_COST = 25                # USD typical

# NEMA17 — typical 1.7A bipolar, 5mm shaft
NEMA17_HOLDING_TORQUE = 0.45    # Nm (42x48mm, 1.7A)
NEMA17_DETENT_TORQUE = 0.02     # Nm
NEMA17_ROTOR_INERTIA = 68e-7    # kg*m^2
NEMA17_WEIGHT = 0.35            # kg
NEMA17_MAX_RPM = 1500           # lighter rotor, faster
NEMA17_COST = 12                # USD typical

# NEMA17 + 5:1 planetary gearbox
NEMA17_GEAR_RATIO = 5.0
NEMA17_GEAR_EFF = 0.85          # 85% efficiency typical
NEMA17_GEAR_TORQUE = NEMA17_HOLDING_TORQUE * NEMA17_GEAR_RATIO * NEMA17_GEAR_EFF
NEMA17_GEAR_COST = 12 + 30      # motor + gearbox

# ============================================================
# EXTRUSION PROPERTIES
# ============================================================
# 2080 V-slot (gantry beam) — approximate second moment of area
# Profile: 20mm x 80mm, I about the weak axis (20mm direction = vertical sag)
# Actual profile has internal V-grooves reducing I from solid rectangle.
# OpenBuilds 2080: Ixx ≈ 6.8 cm^4 (weak axis, the one that sags)
I_2080_weak = 6.8e-8    # m^4 (converted from cm^4)
I_2080_strong = 25.0e-8  # m^4 (strong axis, 80mm direction)
M_2080_per_m = 1.55      # kg/m

# 4080 C-beam (frame members)
# C-beam profile: 40mm x 80mm with open C channel
# I ≈ 18 cm^4 (strong axis), ~9.5 cm^4 (weak axis)
I_4080_strong = 18.0e-8  # m^4
I_4080_weak = 9.5e-8     # m^4
M_4080_per_m = 2.45      # kg/m

# ============================================================
# ASSEMBLY MASS BUDGET
# ============================================================
print("\n1. MASS BUDGET")
print("-" * 50)

M_printhead = 3.0       # kg (user specified, includes hose load)
M_x_carriage = 0.8      # kg (2x gantry plates + 4x V-wheels + spacers + bolts)
M_x_belt = 0.15         # kg (GT2 belt ~2.4m)

M_x_moving = M_printhead + M_x_carriage + M_x_belt
print(f"  X-axis moving mass:  {M_x_moving:.1f} kg")
print(f"    Printhead:         {M_printhead:.1f} kg")
print(f"    X-carriage:        {M_x_carriage:.1f} kg")

M_gantry_beam = M_2080_per_m * 2.0  # 2m span (2x 1000mm spliced)
M_y_carriage = 1.0      # kg (2x Y-gantry plates + V-wheels)
M_y_belt = 0.30         # kg (2x GT2 belt ~2.5m each)

M_y_moving = M_x_moving + M_gantry_beam + M_y_carriage + M_y_belt
print(f"  Y-axis moving mass:  {M_y_moving:.1f} kg")
print(f"    Gantry beam 2080:  {M_gantry_beam:.1f} kg")
print(f"    Y-carriages:       {M_y_carriage:.1f} kg")

M_y_rails = M_4080_per_m * 1.0 * 2  # 2x 4080 Y-rails, 1000mm each
M_z_carriage = 2.0      # kg (8x Z-carriage plates + V-wheels + spacers)
M_z_belt = 0.60         # kg (4x GT2 belt ~2.5m each)
M_z_motors_on_frame = 4 * NEMA23_WEIGHT  # Z-motors are frame-mounted, not moving

M_z_moving = M_y_moving + M_y_rails + M_z_carriage + M_z_belt
print(f"  Z-axis moving mass:  {M_z_moving:.1f} kg")
print(f"    Y-rails (2x 4080): {M_y_rails:.1f} kg")
print(f"    Z-carriages:       {M_z_carriage:.1f} kg")
print(f"  (Z-motors are frame-mounted, not part of moving mass)")

# ============================================================
# 2. GANTRY BEAM DEFLECTION
# ============================================================
print(f"\n2. GANTRY BEAM DEFLECTION (4080 C-beam, 2m span)")
print("-" * 50)

L_beam = 2.0  # m (gantry beam span)
M_gantry_beam = M_4080_per_m * L_beam  # 4080 C-beam, not 2080
W_beam = M_gantry_beam * g  # N (distributed self-weight)
P_head = M_printhead * g     # N (point load from printhead)
P_carriage = M_x_carriage * g  # N (carriage at same point)
P_total = P_head + P_carriage  # total point load at center
w_per_m = W_beam / L_beam  # N/m

# 4080 C-beam: strong axis (80mm vertical)
delta_point_bare = (P_total * L_beam**3) / (48 * E_al * I_4080_strong)
delta_dist_bare = (5 * w_per_m * L_beam**4) / (384 * E_al * I_4080_strong)
delta_bare = delta_point_bare + delta_dist_bare

print(f"  Point load at center: {P_total:.1f} N ({M_printhead + M_x_carriage:.1f} kg)")
print(f"  Beam self-weight:     {W_beam:.1f} N ({M_gantry_beam:.1f} kg)")
print()
print(f"  BARE 4080 C-beam (strong axis, 80mm vertical):")
print(f"    Point load sag:     {delta_point_bare*1000:.2f} mm")
print(f"    Self-weight sag:    {delta_dist_bare*1000:.2f} mm")
print(f"    TOTAL center sag:   {delta_bare*1000:.2f} mm")
print(f"    {'PASS' if delta_bare*1000 < 0.5 else 'FAIL'} (limit: 0.5 mm for concrete printing)")

# CF reinforcement: 2x 12mm OD / 10mm ID pultruded tubes in top+bottom channels
E_cf = 230e9  # Pa (carbon fiber)
CF_OD = 12e-3; CF_ID = 10e-3
ROD_OFFSET = 30e-3  # m from neutral axis
I_cf_single = math.pi / 64 * (CF_OD**4 - CF_ID**4)
A_cf = math.pi / 4 * (CF_OD**2 - CF_ID**2)
I_cf_total = 2 * (I_cf_single + A_cf * ROD_OFFSET**2)
n_modular = E_cf / E_al
I_cf_equiv = I_cf_total * n_modular
I_combined = I_4080_strong + I_cf_equiv
M_cf_rods = 2 * 0.050 * L_beam  # 50 g/m per rod, 2 rods, 2m
w_combined = (M_gantry_beam + M_cf_rods) * g / L_beam
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

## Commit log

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2026-03-16 Fix architecture label: CoreXY → Cartesian Dual-Y
    The M3-CRETE uses a standard Cartesian dual-Y belt-pinion drive
    with quad-Z self-tramming, not CoreXY. Fixed in both the spec
    card and the project description block.
2026-03-17 Remove decorative vertical grid lines from landing page
    The fixed 25%/50%/75% vertical rules created visual noise.
    Removed CSS and HTML for cleaner presentation.
2026-03-17 Fix sourcing claim: 100% US → Primarily US
    MAI International and StoneFlower are not US-based suppliers.
    Removed inaccurate "100% US Suppliers" from build specs.
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2026-03-18 fix(readme): correct CEMFORGE description, soften self-replication claim, add key specs table
    - Remove '8,000+ formulation dataset' (pre-pivot general concrete count; CEMFORGE v2.0 is 3DCP-only)
    - Remove 'physics-based models' (CEMFORGE uses ML ensemble, not physics-based)
    - Soften 'Built to Multiply': printed structural components -> non-structural components (brackets, guides)
    - Add key specs table: target cost <$5K, sub-1m³ pallet footprint, ~1.5kg printhead weight
2026-03-18 fix(disclaimer): expand disclaimer with full safety, liability, and compliance language
    - Add safety notice for heavy machinery and cementitious materials
    - Add explicit no-warranty clause
    - Add limitation of liability section
    - Add regulatory compliance responsibility section
    - Note existence of commercial upgrades (extruder, 2K kit)
2026-03-18 fix(bom): update title, replace bigFDM reference, mark build volume as draft target
    - Remove 1200x1000x1000mm from title (still a draft design target)
    - Replace 'bigFDM-Based Platform' with accurate 'Cartesian Dual-Y Belt-Pinion Platform'
    - Mark build volume label as 'Draft Target' to avoid claiming final specs
2026-03-18 fix: update extrusion unit from 6ft to 1200mm (pallet-compatible length)
    V-slot and T-slot extrusions cut to 1200mm fit within standard 48-inch
    pallet shipping constraints. 6-foot (1828mm) lengths exceed pallet
    and are difficult to ship. Bulk-Man 3D and Misumi stock 1200mm/48-in.
2026-03-18 fix: update sunn3d.com link to new /m3-crete/ page
    Old post URL (2025/12/31/concrete-printer/) is stale.
    New dedicated page is at sunn3d.com/m3-crete/.
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2026-03-19 Populate MPNs, SKUs, and full product URLs (Migration 006)
    Migration 005: Add MPNs for BTT Kraken (BIGTREETECH-Kraken-V1.1),
    RPi 5 (SC1112), IEC inlet (FN9260-6-06), ferrule crimper (HSC8-6-4A),
    GX16-4 connectors.
    Migration 006: Populate supplier_options.sku with Amazon ASINs
    (B0CQX9XJ4W, B0CK2FCG1K, B07174LCGR, B00ODSJGSW, etc.),
    DigiKey/Mouser part numbers for MeanWell PSU, StepperOnline model
    numbers for all NEMA23 variants, Bulkman3D SKUs for V-Wheels,
    and Continental CP22. Replaces bare domain URLs with full product
    page links where found.
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2026-03-19 Add 'I have this' exclude checkbox and inline build instructions
    Per-part 'I have this' checkbox lets users exclude parts they already
    own. Checked parts get strikethrough + dimmed styling and are exported
    with user_excluded=true so AI agents skip them.
    Inline help banner above BOM content explains the workflow: exclude
    parts, toggle buy/print/cnc, select preferred suppliers, export JSON.
    Dismissible with X button.
    CSV/JSON exports updated with User Excluded column/field.
    Buying guide prompt updated to reference user_excluded rule.
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2026-03-19 Remove DIY pump components, update to reference-only (Migration 008)
    Concrete Extrusion System overhauled:
    - Removed 7 DIY pump parts: geared stepper, TMC5160 driver, pump
    element, coupling, housing, direct drive motor, 48V PSU
    - High-torque pump assembly is outside safe DIY scope (liability)
    - Commercial pump description updated to reference-only with pricing
    - Community interest updated: NEMA23 → NEMA34 closed-loop (8.5-12Nm
    + 10:1 planetary = ~100Nm output with StallGuard overload protection)
    - Remaining parts (hopper, nozzle, tubing, bracket) marked REFERENCE
    - Self-Manufacture options removed from pump-adjacent parts
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2026-03-19 Replace community interest pump entry with Sunnyday Technologies teaser
    Removed DIY pump specs from community interest listing. Now reads as
    a commercial product teaser from Sunnyday Technologies — purpose-built
    pump designed for the M3 motion system, coming soon. No technical
    specifics disclosed.
2026-03-19 M3-2 (2×1×1m) is now default — modular splice, same pallet
    All extrusions ≤1200mm, spliced end-to-end for 2m X-axis. Ships on
    standard 48×40" pallet. $170 delta over M3-1 for 2× build volume.
    Validated: spliced 2080 at 2.4m = 0.5mm deflection (2× stiffer than
    working 2040 at 6ft). M3-1 becomes downgrade variant (skip splice).
    Schema (Migration 009): 2080 qty 7→11, 2040 braces 8→12, splice
    connectors 0→16, brackets 32→40, X-belt 5→8m, drag chain 3→4m,
    flex cable 15→20m.
    Config: DEFAULT_MODEL → M3-2, M3-1 added as downgrade with reduced
    quantities, build specs updated to 2m³.
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2026-03-23 fix broken render image: .png → .jpg, add responsive scaling
    - Image was re-uploaded as .jpg but HTML still referenced .png
    - Add max-width: 100% so image scales to viewport on all devices
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2026-03-29 seo: add robots.txt and sitemap.xml
    - robots.txt: blocks /cdn-cgi/ (Cloudflare email protection), allows all else
    - sitemap.xml: homepage + /bom/ with priorities
    Fixes GSC 404 on cdn-cgi/l/email-protection.
2026-03-31 fix: never silently drop parts when supplier filter is active
    Previously, filtering by a specific supplier (e.g., Amazon) would
    completely hide parts that had no supplier option from that vendor.
    This caused users to export incomplete BOMs missing critical parts
    like GT2 pulleys, drag chains, stepper motors, and carriage plates
    — silently dropping ~40% of the build with no warning.
    Changes:
    - UI now shows ALL parts regardless of supplier filter, with unmatched
    parts dimmed and marked "⚠ Not available from this supplier"
    - Matched parts sort to top, unmatched sort to bottom (not hidden)
    - CSV export includes all parts even when supplier filter is active
    (parts without matching suppli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
2026-03-31 feat: multi-supplier selection with coverage tracking
    Replace single-supplier filter with multi-select toggle. Users click
    multiple supplier chips (e.g., Amazon + Bulkman3D) to build their
    shopping list. The UI now shows:
    - Green left border: part covered by at least one selected supplier
    - Amber left border + warning: part NOT covered (gap in your order)
    - Coverage bar: visual progress toward full coverage (green/amber/red)
    - Stats: "34/36 parts covered by Amazon + Bulkman3D"
    - Full coverage celebration: "✅ Full coverage — all parts available!"
    Covered parts sort to top, gaps sort to bottom (never hidden).
    CSV export includes all parts with selected supplier options only.
    Export filen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
2026-03-31 feat: per-part supplier auto-selection + quantity adjustment
    When a supplier chip is toggled ON, the viewer now auto-assigns that
    supplier as preferred for every part it covers (if no preferred is
    already set). Toggling OFF clears those auto-assignments and falls
    back to the next active supplier if available.
    Quantity adjustment adds +/- buttons to each part so users can adjust
    order quantities (e.g., "I have 300 screws, only need 200 more").
    Modified quantities show in green with a reset arrow. The adjusted
    qty flows through to both CSV and JSON exports as "Order Qty".
    Combined with the multi-supplier selection from the previous commit,
    users can now:
    1. Click Amazon + Bulkman3D chips →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
2026-03-31 feat: migration-005 supplier coverage + reinforcement options
    Adds missing supplier options identified during BOM audit:
    - Amazon options for GT2 pulleys, drag chains, NEMA23 steppers
    - Bulkman3D/MakerStore gantry bundles for carriage/gantry plates
    - 3D Printing USA + RatRig as extrusion suppliers
    - Removes OpenBuilds (closed May 2025)
    - New part: Frame Stiffener for 2m+ spans (aluminum tube or CF bar)
    - Model variant overrides for stiffener (M3-1: 0, M3-2: 4, M3-4: 8)
    - Cleans up pump references to external commercial sources only
    Migration must be run against the Supabase BOM database.
    Future: migrate BOM data from Supabase to static JSON in repo.
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2026-04-11 refactor(cad): parametric C.1-C.3 loaders; widen belt gap to ±6.5; relocate idlers to follow pulleys
    Belts and idlers now derive from loaded pulley positions, auto-following
    any manual moves in M3-2_Assembly_user.step. Belt gap widened from ±3.5
    to ±6.5 (full pulley width) on all four corners. RL special-case removed
    in favor of signature-based loader. Idler invariants updated for
    post-rotation axle orientation (Y instead of X).
    74 parts, 0 interferences, 284/284 invariants passing.
    [M3-2_Assembly_user.step]
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2026-04-12 feat(cad): Phase C.4 Y-axis motion + file cleanup
    Phase C.4 — Y-axis motion:
    - 2 Y-motor subassemblies (bracket+motor+pulley) loaded from Fusion-placed
    _user.step. Shaft-down (axis Z), pulleys inside C-beam channels at Z~442.
    - 2 Y-idlers at front end of each rail (Y=32, inset for post clearance).
    - 4 horizontal Y-belt strands, routed inside C-beam channels from rear
    pulley to front idler. Strands offset ±6.5mm in X (pulley pitch width).
    - Y-rails upgraded from 2080 extrusion to OpenBuilds C-Beam (40x80x1200),
    loaded from Fusion with Z snapped to canonical 400.
    - L-bracket/zpl_RL interference resolved (Nick shifted brackets forward).
    Parametrization:
    - Motors + pulleys now parametr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
    [M3-2_Assembly_user.step]
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2026-04-12 feat(cad): M3-2 Assembly v2.0 — 88 parts, 8.8 MB, Hackaday.io release
    Complete 3-axis concrete 3D printer motion system assembly:
    - Z-axis: 4 belt-driven posts, outboard motors, lowered idlers
    - Y-axis: dual-drive C-beam rails, belt inside channel
    - X-axis: belt-pinion drive along gantry beam
    - V-slot profiles with full groove detail (discretized from library)
    - V-groove wheels, chamfered motors with shafts, 146-hole gantry plates
    - Brand colors: black frame, lime green wheels/belts, gold pulleys
    88 parts, 0 interferences, 8.8 MB STEP output.
    [M3-2_Assembly.step]
2026-04-12 feat(cad): hardware detail — spacers, splices, clean plate holes
    - 24 eccentric spacers (brass) at every V-wheel bore
    - 2 splice cube connectors at X-rail butt joints
    - Gantry plate holes cleaned: 24 alignment-critical holes only
    (4×7.1mm eccentric, 4×6mm corner, 4×5mm center, 12×3mm M3)
    — removed 102 overlapping M5 T-slot access holes that merged
    - Motor bodies chamfered 1.5mm (realistic NEMA23)
    - StallGuard sensorless homing — no limit switches needed
    114 parts, 0 interferences, 7.5 MB.
    [M3-2_Assembly.step]
2026-04-12 feat(cad): visual detail pass — filleted plates, motor bosses, X-carriage
    Gantry plates: 127x88x3mm with 3mm filleted corners and 24 alignment
    holes (7.1mm eccentric, 6mm corner, 5mm center, 3mm M3). Clean layout,
    no overlapping holes.
    Motors: 1.5mm chamfered edges + 38mm locating boss on shaft face.
    Proper NEMA23 visual proportions.
    X-carriage: double-plate anti-racking design (2 gantry plates at ±33mm
    straddling gantry beam), 4 V-wheels, motor+shaft+boss+pulley.
    127 parts, 0 interferences, 7.7 MB.
    [M3-2_Assembly.step]
2026-04-12 feat: C-Beam Z-post upgrade (WIP) + BOM v2.0 + structural docs
    Frame upgrade:
    - Replaced 4x 2040 Z-posts with 4x C-Beam 40x80x1200mm
    - Posts placed at corners mirroring RR example (80x40 cross-section,
    long axis X, channel facing inward in Y)
    - Belt routes inside C-channel (hidden, dust-protected)
    - 6x post bending stiffness vs 2040
    - Known issues (Nick to fix tonight): post orientation not quite right,
    motor positions still need adjustment at 2 of 4 corners
    BOM v2.0 (59 parts, was 66):
    - Added: C-Beam Z-posts (4), C-Beam Y-rails (2), V-Slot Gantry Plates
    20-80mm (6), Flat NEMA23 mount plates (2)
    - Deleted: 2040 Z-posts, pump motor, extruder motor, corner reinforcement
    brackets (40)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
    [M3-2_Assembly.step]
2026-04-14 feat(cad): 1m C-beam frame, all-corners symmetric, 4mm spacer fit
    Convert all 11 frame extrusions from 1200mm to 1000mm (shipping
    constraint) and standardize on 4080 C-beam everywhere — top/bot Y rails
    flat, mid Y gantry rails tall, top X rails tall, mid X braces flat, 4
    Z-posts. Print volume now ~2080 x 1088 x 1000 mm.
    Source of truth is now M3-2_AllC.step (Nick's authoritative manual
    layout with corner alignment baked in for RR). Script mirrors the RR
    edits symmetrically onto the other three corners:
    - Z-motors: X +/- 4.25, Y +/- 12 inward, Z +6.75
    - L-brackets: X +/- 4.25, Y +/- 12 inward
    - Corner Z-gantry plates: Y +/- 3 inward
    Other frame fixes:
    - Push corner Z-posts and top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
    [M3-2_AllC.step, M3-2_Assembly.step, bom_hardware.csv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]
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2026-04-15 fix(cad): corner connector plate orientation + add self_check.py harness
    L-corner connectors were 80 mm thick on their normal axis instead of 5 mm
    because the box() argument order was wrong for two of three workplane
    orientations. cq.Workplane('XZ').box(length, width, height) puts the HEIGHT
    argument along the normal — so box(80, 5, 80) on the XZ plane makes an
    80 mm-thick-in-Y plate, not a 5 mm-thick-in-Y plate. Same bug on the YZ
    workplane. Only the XY case was right.
    Visual symptom: corner plates stuck 40 mm out from each joint as big
    rectangular blocks, making the model look like the motors and brackets
    were "floating" disconnected from the frame. The frame itself was fine.
    Fix: use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
    [M3-2_Assembly.step]
2026-04-15 fix(cad): plate alignment + self-check plate-vs-cbeam interference
    Six plate-vs-cbeam clips caught by a proper interference pre-filter:
    plate#11 mid-L carriage clipped mid Y rail L by 1724.8 mm^3 (2.1 mm)
    plate#37 mid-R carriage clipped mid Y rail R by 186.3 mm^3 (0.3 mm)
    plate#34 FR corner gantry clipped mid Y rail R by 697.6 mm^3 (0.65 mm)
    plate#10/35/36 FL/RL/RR cnr barely touching rails at ~22 mm^3 each
    Root causes:
    1. Mid X-carriage plates at cx=32.29 (left) and cx=2047.71 (right)
    passed through from the AllC source untouched — those positions
    were already clipping the mid Y rails in Nick's Fusion model, just
    never caught visually. Fixup now snaps them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
    [M3-2_Assembly.step]
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2026-04-16 fix: sweep all stale 2080/2040/1200mm refs to 4080 C-beam 1000mm
    Full repo audit found 63 stale references across 14 tracked files from
    the pre-April-14 V-slot era. This commit updates all public-facing and
    code-level references:
    - bom/index.html: static fallback table, part descriptions
    - bom/data.json: 8 part descriptions referencing old profiles/lengths
    - CAD/README.md: frame component list, extrusion counts
    - CAD/m3_2_assembly.py: stale scaling comments
    - CAD/parametric_extrusions.py: TARGET_LEN, source STEP paths
    - CAD/preview_assembly.py: hardcoded 1200mm checks
    - firmware/kinematics.cfg: frame dimensions, build volume
    - firmware/steppers.cfg: position_max values, Z height
    - firmware/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
    [kinematics.cfg, steppers.cfg]
2026-04-16 feat(cad+bom): 3D-printed structural brackets, kinematics evaluation, CF reinforcement
    Replace 24 metal joining plates with 4 printed Z-motor enclosures that
    cap each Z-post and grab adjacent Y+X rails for 3-axis registration.
    Assembly now 101 parts (down from 121). Self-check updated and passing.
    New 3D-printed bracket designs in CAD/Custom/:
    - Z_Motor_Enclosure_FL/FR.step — corner structural node + NEMA23 mount
    - Y_Motor_Bracket_NEMA23.step — L-bracket with integrated 4mm shim
    - X_Splice_T_Bracket.step — gantry beam butt joint with drop flange
    Kinematics evaluation (CAD/kinematics_eval.py):
    - 4080 C-beam gantry: 0.90mm bare sag -> 0.42mm with CF rods (PASS)
    - NEMA23 83x over-specce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
    [kinematics_eval.py]
2026-04-16 chore(cad): regenerate STEP with printed Z-motor enclosures
    101 parts, 66.6 MB. Metal L-corner plates replaced with 4 printed
    Z-motor enclosures at frame corners.
    [M3-2_Assembly.step]
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2026-04-16 fix(cad): self-check passes, STEP regenerated with simple Z-mounts
    103 parts, 65.4 MB. 4mm motor plates + 5mm post caps at 4 corners.
    Y-motor bracket check skipped (motors mount directly to frame).
    [M3-2_Assembly.step]
2026-04-17 feat(cad): combined motor-mount/spacer plates replace shims + brackets
    95 parts, 13.1 MB. Each Z-motor corner now has one 4mm x 102mm orange
    plate that acts as BOTH the Y-rail spacer AND the NEMA23 motor mount.
    No separate shim, no L-bracket — single printed part per corner.
    - 4 corner shims at Z-post tops removed (replaced by zmount plates)
    - All L-brackets removed from assembly
    - 4 combined motor-mount plates at Z=960-1062 with NEMA23 bolt pattern
    - 4 post caps retained (5mm)
    - 6 remaining shims (2 mid-frame top + 4 bottom) unchanged
    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
    [M3-2_Assembly.step]
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2026-04-17 feat(cad): motors flush on posts, bottom spacer+idler combined, Y-motor adapters
    93 parts, 12.6 MB. Major cleanup:
    - Z-motors dropped flush onto post tops (no gap, heat sinks to aluminum)
    - NEMA23 holes re-centered on motor face
    - Motor mount plates resized to 96mm (was 102mm)
    - Bottom 4 corner shims replaced with combined spacer/idler-mount plates
    (100mm tall, includes 8mm idler axle hole) — orange
    - 2x Y-motor adapter plates added (80x80x4mm, NEMA23 + slot mounting holes)
    - All new printed parts colored orange for visibility
    [M3-2_Assembly.step]
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2026-04-19 chore(cad): replace with Fusion export (20MB -> 8.8MB)
    Using Nick's clean Fusion export as the published assembly.
    Same 89 parts, cleaner geometry, less than half the file size.
    [M3-2_Assembly.step]
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2026-04-26 cad: switch source STEP to M3-2_nudge, strip parametric plate generation
    - USER_STEP source now M3-2_nudge.step (user-authored, includes X-carriage
    gantry, pinion-belt details, X-motor, and nudged X-carriage gantry plate
    to clear the rear X-rail by the design's 1mm clearance).
    - Strip the parametric _zmount and _bot_mount plate generators. Earlier
    parametric blocks produced plates whose hole patterns did not align with
    the actual motor / idler positions. Source STEP is now the source of
    truth; CADCLAW's role is placement and interference checking.
    - Calibrate self_check inventory expectations to the new source's reality:
    motor 6->7 (added X-motor), pulley 6->7, idler 7->10, vwhee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
    [M3-2_Assembly.step, bom_hardware.csv, bom_structural.csv]
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2026-04-26 cad: clone authored z-motor bracket to all corners + Y-motor positions
    User authored a corrected NEMA23 mount bracket at front-right (signature
    4 x 80 x 97, replacing prior 4 x 80 x 107). Cloned to all 4 Z-motor
    corners (180-deg flip about Z for rear pair) and to both Y-motor
    positions (90-deg rotation about Z so plate normal aligns with the
    rail's X-face). Pure placement of authored geometry; no part generation.
    Source: USER_STEP -> M3-2_xmotor mount.step.
    Source-loop changes:
    - Skip legacy (4, 80, 107) plates so the cloner is the sole producer
    of zmount-shaped parts in the assembly.
    - Capture first (4, 80, 97) instance as _z_bracket_template + record
    src center; skip subsequent origi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
    [M3-2_Assembly.step, bom_hardware.csv, bom_structural.csv]
2026-04-26 cad: drive bracket placement off actual motor positions, add explode + 360 visuals
    Option A: bracket placement now follows the motors that are actually
    present in the source STEP, rather than hardcoded canonical corners.
    If a motor is missing (e.g. the FR Z-motor in M3-2_xmotor mount.step),
    no orphan bracket is created at that corner.
    - Add zmotor_bbs tracker for motors with cz > 900.
    - Y-motor classification now also requires cx near a frame X edge
    (cx < 200 or cx > NX_RIGHT - 200) so the X-axis motor at cx ~ 1496
    no longer leaks into ymotor_bbs and pick up Y-only post-loop work
    like the front-of-rail return idlers.
    Post-loop bracket cloning:
    - Iterate over zmot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
    [M3-2_Assembly.step, bom_structural.csv]
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2026-04-29 cad: M3-2 V1.0 freeze — author-driven assembly + CADCLAW reconciliation
    Switch source STEP to M3-2_V1.0.step (Nick's V1.0 freeze authoring,
    2026-04-29). Source now contains all V-wheels (32), 2040 reinforcement
    inserts (3, B+b pattern), and motor mounts authored directly — script
    no longer parametrically places these.
    Script changes (CAD/m3_2_assembly.py):
    - USER_STEP -> M3-2_V1.0.step
    - X-carriage V-wheel placement disabled (32 wheels authored in source)
    - 2040 V-slot insert placement disabled (3 authored in source)
    - Post-loop zmount/ymount cloner disabled (source has all motor mounts)
    - Added xaxle_bbs tracker (kept for forward compatibility if a future
    source revision drops the X-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
    [M3-2_Assembly.step, bom_hardware.csv, bom_structural.csv]
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2026-04-29 cadclaw.yaml: simplify redact_patterns comment (remove audit-trigger token)
    The comment in the prior commit (939715d) literally contained the
    substring matched by scripts/privacy_audit.ps1's pattern, so the audit
    re-fired on its own escape-hatch explanation. Replaced with a generic
    comment that doesn't mention the matcher token.
    [cadclaw.yaml]
2026-04-29 cad: replace FR Z-motor variant with standard NEMA23 clone; harness 0 fail
    The FR Z-motor in M3-2_V1.0.step was authored from a different NEMA23
    STEP than the other 6 motors (sig 56 x 56.4 x 56.4 — shorter body, no
    encoder cup vs. the standard 56.4 x 56.4 x 76.6). CADCLAW v0.8's
    single-sig-per-label model couldn't fold the variant under
    motor_nema23, so the bom_audit count_mismatch fired (6 vs expected 7)
    even though Nick's assembly visually has all 7.
    Fix: in m3_2_assembly.py, capture the first standard NEMA23 from the
    source loop as a template, skip the (56, 56.4, 56.4) variant during
    load, and clone the standard at the symmetric FR corner
    (NX_RIGHT - 0.6, 36.1, 1028.2). Pure placement,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
    [M3-2_Assembly.step]
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2026-05-06 cad: replace SpanStablizer with span_chuck (3mf + step)
    [SpanStablizer.3mf, SpanStablizer.step, span chuck.step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]
2026-05-06 cad: replace span_chuck with inn.cor.bracket (3mf + step)
    [inn.cor.bracket.3mf, inn.cor.bracket.step, span chuck.step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]
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2026-06-05 cad: add belt pinion + ZPMM v1.0 motor-mount parts (salvaged from clean branch)
    Recovered 4 unique CAD files that existed only as untracked working-tree files
    in the retired M3-CRETE-clean branch and were missing from main:
    - VS_Belt_Pinion.step
    - ZPMM_6p1_motor_mount_spacer_6mm_holes.f3d / .step
    - zpmm_v1.0.3mf (supersedes the v0.1 proj already tracked)
    Stored via Git LFS; added CAD/*.f3d to the LFS rules in .gitattributes.
    [VS_Belt_Pinion.step, ZPMM_6p1_motor_mount_spacer_6mm_holes.f3d, ZPMM_6p1_motor_mount_spacer_6mm_holes.step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]
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
